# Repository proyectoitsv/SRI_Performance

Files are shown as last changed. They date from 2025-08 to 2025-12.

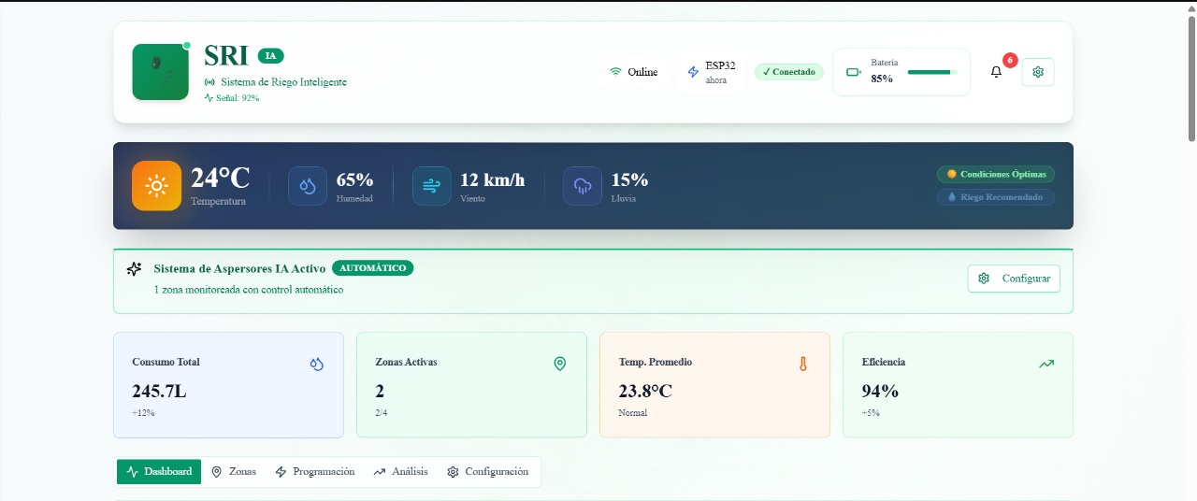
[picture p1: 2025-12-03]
INTERFAZ GRAFICA/IMAGEN_INTERFAZ1.jpg

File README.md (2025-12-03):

# SRI Performance
Sistema de Riego Inteligente sectorizado y autónomo.

## Descripción
SRI Performance es un sistema de riego inteligente que utiliza un ESP32, sensores de humedad y un aspersor direccionable en dos ejes (X–Y) para regar únicamente donde es necesario. Optimiza el uso del agua y mantiene el césped saludable sin intervención constante.

## Características
- Riego automático basado en humedad real del suelo.
- Aspersor 2D (X–Y) para direccionar el riego por sectores.
- Control desde pantalla local o mediante Wi-Fi/Bluetooth.
- Ahorro de agua superior al 20–40% en comparación con métodos tradicionales.
- Instalación prolija con cañerías y cableado subterráneo.
- Seguridad: evita encharcado, bloqueos y riego en horarios inadecuados.

## Tecnologías utilizadas
**Hardware:** ESP32, servomotores, bomba de agua, aspersor direccionable, display.  
**Sensores:** humedad de suelo, temperatura ambiente.  
**Software:** Arduino IDE / PlatformIO.  
**Comunicación:** Wi-Fi y Bluetooth.

## Funcionamiento
1. Los sensores miden humedad y temperatura.  
2. El ESP32 evalúa si es necesario regar.  
3. El aspersor se mueve hacia el sector requerido.  
4. La bomba activa el riego únicamente en esa zona.  
5. El sistema se detiene al alcanzar la humedad adecuada.

## Impacto esperado
- Ahorro significativo de agua en jardines y espacios residenciales.  
- Reducción de costos de mantenimiento.  
- Uso más responsable de los recursos hídricos.

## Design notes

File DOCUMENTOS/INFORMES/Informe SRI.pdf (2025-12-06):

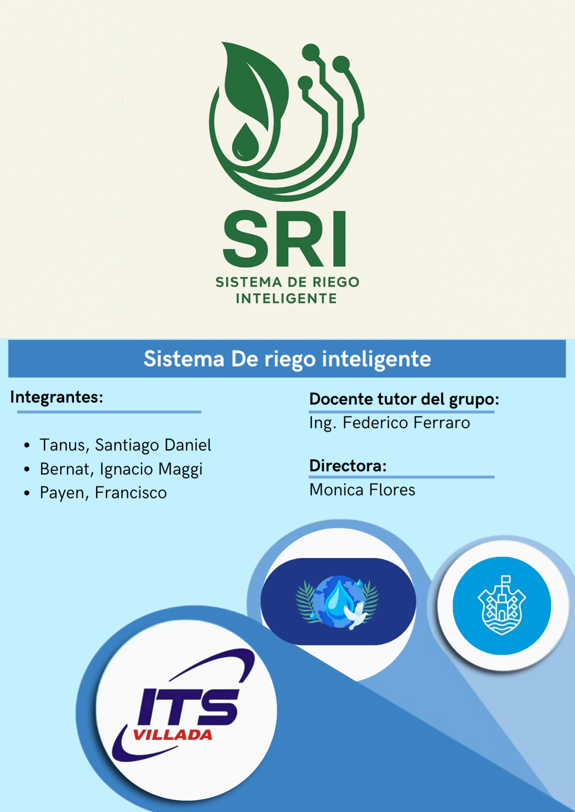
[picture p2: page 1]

Proyecto Final Electronica - ITS Villada 2025
“Miles han vivido sin amor,

# ninguno sin agua ”

### - W. H. Auden

# Introducción

El presente informe forma parte del Proyecto Final del Instituto Técnico Salesiano Villada. Este documento busca plasmar el recorrido del proceso llevado a cabo por el equipo de estudiantes, quienes asumieron el desafío de abordar una problemática real vinculada al uso ineficiente del agua en entornos urbanos y proponer una solución tecnológica que responda a las necesidades identificadas.

El proyecto seleccionado consiste en el diseño y construcción de un Sistema de Riego Inteligente (SRI) orientado al riego de césped y jardines domiciliarios. La propuesta combina electrónica, programación y criterios agronómicos con el objetivo de optimizar el consumo de agua potable, manteniendo a la vez la calidad de los espacios verdes y reduciendo el impacto ambiental asociado al desperdicio hídrico.

El proceso de trabajo se enmarca en un enfoque metodológico que abarcó desde la identificación y análisis del problema hasta la conceptualización, diseño, construcción y validación de un prototipo funcional. Este camino permitió aplicar los conocimientos adquiridos en áreas como electrónica, programación, diseño técnico y automatización, consolidando así las competencias propias del perfil profesional técnico.

La búsqueda de soluciones se realizó teniendo en cuenta criterios de factibilidad, impacto y utilidad. El sistema propuesto no solo incorpora innovación y tecnología, sino que además se alinea con principios de sostenibilidad y uso responsable del agua, aportando una herramienta concreta ante una problemática ambiental vigente.

# Análisis de la problemática

### 1.1 Contexto hídrico global y urbano

El agua potable recorre un largo trayecto desde las plantas purificadoras hasta los hogares, donde se destina a usos esenciales como la higiene, la alimentación y el saneamiento. Sin embargo, diversos estudios señalan que una fracción considerable de este recurso se destina a usos no vitales y, en muchos casos, bajo esquemas de consumo poco eficientes.

En el ámbito urbano, el riego de césped y jardines representa uno de los principales focos de consumo dentro del uso domiciliario. La Environmental Protection Agency (EPA) estima que el riego de césped puede representar hasta el 60 % del consumo total de agua de un hogar. En un contexto de creciente escasez hídrica, este porcentaje adquiere un peso crítico.

### 1.2 Riego residencial en Córdoba

ITS Villada | 1.

En la provincia de Córdoba se observa una expansión sostenida de barrios privados y urbanizaciones con superficies importantes de césped y espacios verdes. Tomando como referencia que, para 2022, existían aproximadamente 90 barrios privados, cada uno con un promedio de 300 lotes, se puede dimensionar el impacto del riego sobre el consumo de agua.

Suponiendo que cada vivienda posee unos 100 m² de césped y un riego diario promedio de 5 L/m², se obtiene:

### 90 barrios × 300 lotes × 100 m² × 5 L/m² = 13.500.000 L/día

Este volumen representa únicamente el consumo vinculado al riego domiciliario en barrios privados, sin considerar otros sectores urbanos. Si se asume una eficiencia típica de los sistemas de riego convencionales cercana al 80 %, alrededor de 2,7 millones de litros diarios no se aprovechan correctamente y se pierden por evaporación, drenaje excesivo o malas prácticas de riego.

A lo anterior se suman las viviendas dentro de la ciudad de Córdoba que utilizan riego manual —tradicionalmente menos eficiente—, lo cual incrementa aún más el consumo y las pérdidas totales de agua.

### 1.3 Procesos actuales de riego

En entornos residenciales predominan dos modalidades principales:

- Riego manual, mediante manguera, sin medición de caudal ni control preciso del tiempo.
- Riego automático por aspersores, gobernados por temporizadores que habilitan la apertura del sistema en horarios fijos.

Si bien los aspersores controlados por temporizador presentan una mejor eficiencia que el riego manual, todavía dejan un margen importante de ineficiencia.

# ¿Qué consecuencias tiene?

La pérdida de recursos hídricos en el entorno urbano tiene consecuencias graves que afectan tanto al medio ambiente como a la gestión del recurso.

### 2.1 Impactos ecológicos

El uso ineficiente del agua potable en el riego de césped y jardines tiene impactos ambientales directos:

- Desperdicio de recursos hídricos: Se incrementa la presión sobre las fuentes de abastecimiento, especialmente en períodos de sequía.
- Alteración del ciclo hidrológico urbano: El exceso de riego genera escorrentía superficial que arrastra fertilizantes y contaminantes hacia desagües pluviales y cursos de agua.
ITS Villada | 2.

- Degradación del suelo: El sobre-riego puede deteriorar la estructura del suelo, reducir su capacidad de infiltración y favorecer la erosión, además de lixiviar nutrientes.

### 2.2 Impactos socioeconómicos

Desde el punto de vista socioeconómico, la ineficiencia hídrica implica:

- Aumento del costo del servicio de agua para los usuarios domiciliarios.
- Incremento de la demanda energética asociada a la potabilización, bombeo y distribución de mayores volúmenes de agua.
- Limitaciones y conflictos de uso en épocas críticas, donde los municipios suelen imponer restricciones de riego.

### 2.3 Impactos a nivel urbano y global

A escala urbana y global, el uso ineficiente del agua para riego contribuye a:

- Agravar el estrés hídrico en regiones vulnerables, reduciendo la disponibilidad de agua para usos esenciales.
- Aumentar la huella hídrica de las ciudades.
- Dificultar el cumplimiento de objetivos de sostenibilidad vinculados al uso racional del agua, como el ODS 6 de la Agenda 2030.

# ¿Cómo se puede mejorar la eficiencia del riego?

Existen diversas estrategias para mitigar el uso ineficiente del recurso hídrico.

### 3.1 Modernización y regulación del riego domiciliario

- Implementar sistemas de riego automatizados con sensado real del suelo y del ambiente.
- Regular horarios de riego para evitar pérdidas por evaporación en horas de máxima temperatura.
- Promover ordenanzas municipales que incentiven el uso de tecnologías eficientes.

### 3.2 Alternativas tecnológicas sostenibles

- Incorporar sensores de humedad del suelo y sensores ambientales para regar solo cuando es necesario.
- Utilizar microcontroladores con conectividad, como el ESP32, que permitan monitoreo y control remoto.
- Fomentar la adopción de sistemas de riego por goteo o aspersores de bajo caudal.

### 3.3 Manejo del suelo y programación del riego

- Ajustar la frecuencia de riego en función del tipo de suelo (arenoso, franco, arcilloso) y de la pendiente.
- Programar riegos en franjas horarias de baja evaporación.
ITS Villada | 3.

# Investigación

Se inició el proceso de investigación partiendo de la identificación de una problemática ambiental de relevancia global. Entre los distintos desafíos, se destacó la creciente escasez de agua dulce, un recurso cuya disponibilidad se ve comprometida debido al cambio climático, el crecimiento poblacional y el uso ineficiente en diversos sectores. A partir de este punto de partida, se llevó a cabo un análisis más profundo para comprender en qué ámbitos urbanos se produce un consumo excesivo o poco controlado del agua.

Durante esta etapa se revisaron distintos hábitos y sistemas de uso cotidiano, tales como el consumo doméstico, los procesos industriales y el mantenimiento de espacios verdes. Fue en este último donde se detectó un patrón significativo: el riego de césped y jardines presenta altos niveles de desperdicio debido a prácticas poco eficientes, falta de automatización, escasa supervisión y desconocimiento sobre las necesidades reales de humedad del suelo.

Como resultado de esta investigación, se identificó que el riego manual o los sistemas tradicionales suelen aportar más agua de la necesaria, generando no solo un gasto innecesario del recurso, sino también problemas asociados como el deterioro del césped, el aumento del consumo energético y el impacto económico en los hogares. Este hallazgo se convirtió en el eje central del proyecto, orientado a desarrollar soluciones más inteligentes y sostenibles para el manejo del agua en espacios verdes urbanos.

## Espacios verdes

Tomando como referencia que, para el año 2022, existían aproximadamente 90 barrios privados en la provincia de Córdoba, y considerando que cada uno de ellos cuenta en promedio con unos 300 lotes, es posible estimar el impacto del riego domiciliario de césped sobre el consumo total de agua. Si asumimos que cada vivienda posee alrededor de 100 m² de superficie con césped y que el riego promedio diario requerido es de unos 5 litros por metro cuadrado, se obtiene el siguiente cálculo:

90 barrios × 300 lotes × 100 m² × 5 L/m² = 13.500.000 litros de agua por día.

Este volumen representa únicamente el consumo de las viviendas que utilizan riego automático dentro de barrios privados, sin considerar otros sectores urbanos. Además, si se asume un nivel de eficiencia típico de los sistemas de riego convencionales, cercano al 80%, se puede estimar la magnitud del desperdicio asociado. Un 20% del agua aplicada no llega a aprovecharse debido a pérdidas por evaporación, drenaje excesivo, mala orientación de los aspersores o prácticas de riego inadecuadas.

Esto significa que, de los 13,5 millones de litros utilizados diariamente, aproximadamente 2,7 millones de litros se pierden sin cumplir su función real. Para dimensionar esta cifra, basta con señalar que este volumen equivale, en promedio, al contenido de una pileta olímpica completa desperdiciada cada día.

Cabe destacar que estos cálculos no incluyen a las miles de viviendas ubicadas dentro de la ciudad de Córdoba que también poseen superficies de césped y utilizan riego manual —un método tradicionalmente menos eficiente—, lo que incrementaría aún más el consumo y las pérdidas totales de agua. Este escenario evidencia la necesidad urgente de implementar tecnologías de riego más inteligentes, eficientes y automatizadas que permitan optimizar el uso del recurso y reducir el impacto ambiental asociado.

ITS Villada | 4.

## Procesos actuales de riego

Se analizaron los procesos de riego actualmente utilizados en entornos residenciales y urbanos. Entre ellos, los más comunes son el riego manual y los sistemas de riego automático por aspersores. Si bien estos últimos presentan una mayor eficiencia, con valores que oscilan entre el 75% y el 85%, todavía dejan un margen de ineficiencia de aproximadamente 15%, que al ser extrapolado a grandes superficies representa un volumen significativo de agua desperdiciada.

A partir de este diagnóstico, se inició una búsqueda de alternativas que permitieran incrementar la eficiencia del riego y reducir el desperdicio, poniendo especial atención en las limitaciones que presentan los sistemas actuales. Entre los principales factores identificados se encontró que la mayoría de las instalaciones no considera adecuadamente las variables ambientales que influyen en las necesidades reales de agua del césped, tales como la humedad del suelo, la temperatura ambiente, la radiación solar y la evapotranspiración.

Con el fin de diseñar una solución más precisa y sustentada, se investigó cuál es el tipo de césped más común en la región de Córdoba y cuáles son sus requerimientos hídricos. En particular, se determinó el porcentaje de humedad volumétrica necesario para mantener el césped saludable, así como el valor mínimo en el que la planta alcanza su punto de marchitez permanente, momento en el cual ya no puede recuperarse aun si se la riega posteriormente. Esta información resulta fundamental para definir umbrales de riego inteligentes.

Asimismo, se llevó a cabo una revisión de los tipos de suelo predominantes en la región, dado que la textura, estructura y capacidad de retención hídrica del suelo influyen directamente en la frecuencia y cantidad de riego necesaria. También se incorporó el valor de evapotranspiración (ET) propio de la zona, un parámetro clave que permite estimar la pérdida de agua del suelo y la planta por evaporación y transpiración.

Finalmente, se evaluaron las temperaturas y franjas horarias más convenientes para realizar el riego, priorizando momentos del día en los que la evaporación es mínima (como la madrugada o la noche) y en los que el funcionamiento del sistema no genera molestias para los propietarios. Esta investigación permitió establecer criterios técnicos más precisos para el desarrollo de un sistema de riego automatizado, eficiente y adaptado a las condiciones locales.

ITS Villada | 5.

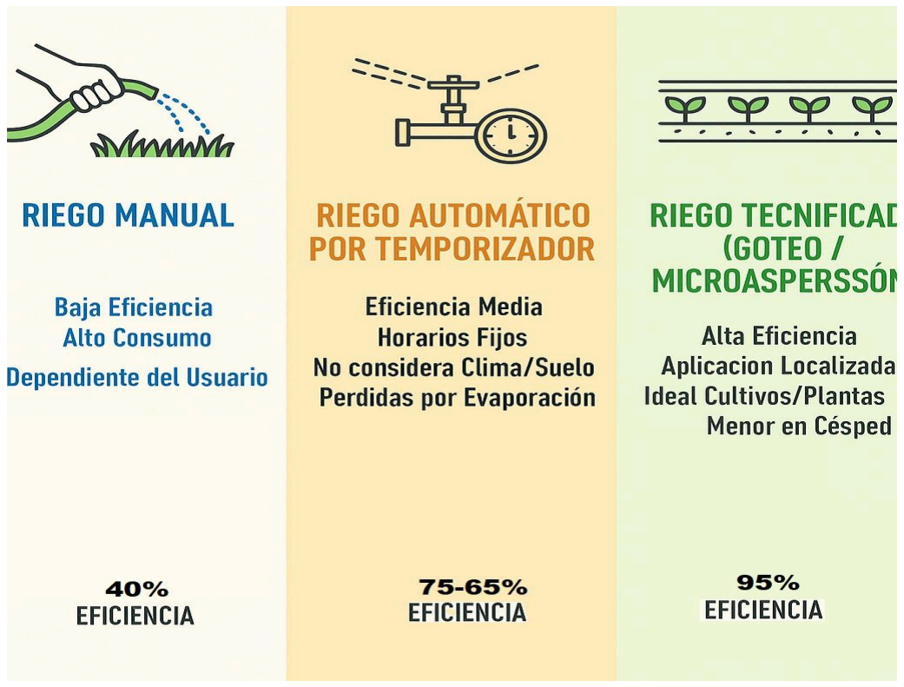
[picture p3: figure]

Figura 1: “Comparativa de sistemas de riego actuales.”

# Solución elegida

Frente a la problemática planteada, se eligió el desarrollo de un Sistema de Riego Inteligente (SRI) como solución tecnológica. La propuesta se enfoca en el ámbito domiciliario y busca:

1. Optimizar el uso del agua en el riego de césped.
2. Integrar sensado de suelo y ambiente.
3. Automatizar la decisión de riego en función de variables reales.

# Sistema de riego propuesto

El Sistema de Riego Inteligente desarrollado consiste en un aspersor automatizado controlado por un microcontrolador ESP32, equipado con:

- Sensores de humedad de suelo
- Sensor de temperatura y humedad ambiente
- Bomba de agua
- Servomotores para orientar el chorro de riego.

El objetivo es lograr un riego sectorizado, que aplique el agua únicamente donde y cuando es necesario, manteniendo la humedad del suelo por encima del 15%

ITS Villada | 6.

# Características del producto mínimo viable

Para garantizar el rendimiento óptimo de nuestro SRI, es esencial incorporar ciertas características fundamentales:

- Medición Inteligente de Humedad: Capacidad de medir con precisión la humedad del suelo en al menos tres puntos, para detectar heterogeneidades y optimizar la distribución del agua.
- Mecanismo Controlado para el Riego: El sistema debe habilitar el riego de forma proporcional a la necesidad, controlando la bomba y la orientación de los aspersores para lograr una cobertura uniforme.
- Sistema de Telemetría: Integración de un sistema que facilite la transmisión de datos en tiempo real (humedad, temperatura, estado de la bomba) y permita una respuesta efectiva desde la estación terrena.
- Sistemas de Orientación: Utilización de servomotores para garantizar la precisión de la ubicación donde se aplica el agua, evitando el riego de áreas no deseadas.
- Estación Terrena: Base operativa para recolectar, monitorear y tomar decisiones sobre el avance del riego. Esta estación recibe los datos telemétricos y permite realizar ajustes en tiempo real.

# Consumo de agua y estimación de ahorro

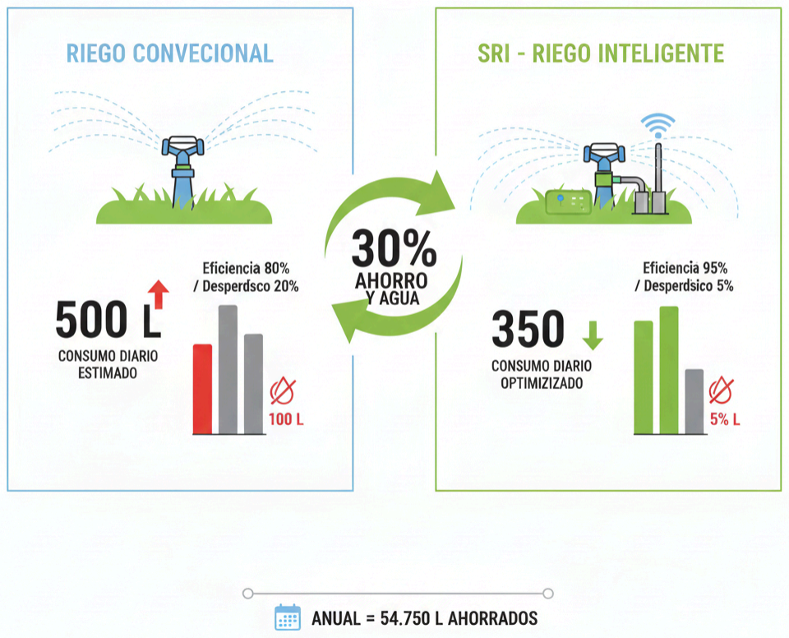
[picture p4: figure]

Figura 2: “Comparativa de consumo hídrico entre sistema convencional y sri.”

ITS Villada | 7.

# Escenario de aplicación

El sistema se dimensionó inicialmente para jardines de entre 50m2 y 150m2 , con tres zonas de riego diferenciadas controladas por la orientación del aspersor.

No obstante, el concepto es escalable a:

- Clubes deportivos
- Espacios verdes
- Pequeñas plazas de barrio.

# Funcionamiento en conjunto

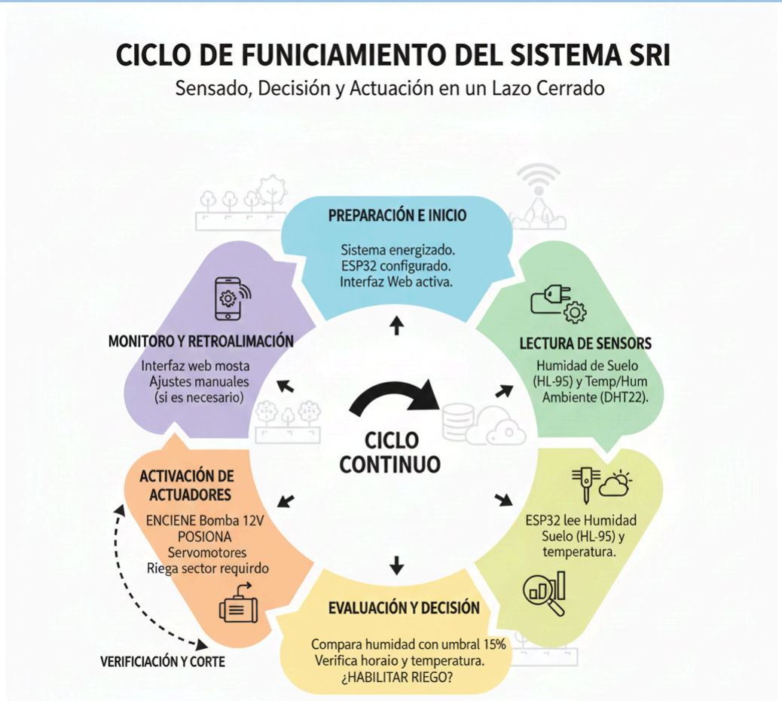
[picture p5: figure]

Figura 3: “Diagrama de flujo de funcionamiento.”

ITS Villada | 8.

# Relevamiento de componentes del sistema

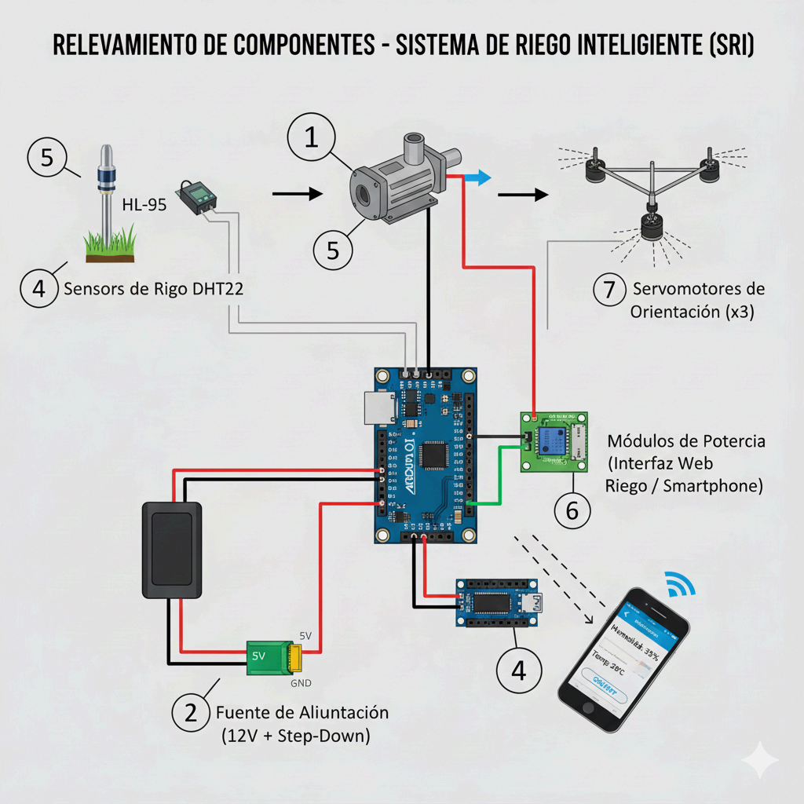
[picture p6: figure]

Figura 4: “Relevamiento de componentes.”

Relevamiento de Componentes del Sistema
1. Microcontrolador Principal - Es el cerebro del sistema. Se encarga de adquirir los datos de los sensores, ejecutar la lógica de decisión de riego (basada en el umbral de humedad) y enviar las señales de control a los actuadores y módulos de potencia.
- Utilizado: ESP32 (Módulo de desarrollo con conectividad WiFi integrada).
2. Sensores de Humedad de Suelo - Miden la resistencia eléctrica del suelo, proporcionando un valor analógico que se correlaciona con el contenido hídrico y permite determinar si se ha alcanzado el umbral crítico para el césped.
- Utilizados: Sensores HL-95 (Resistivos).
3. Sensor Ambiental - Captura las condiciones atmosféricas (temperatura y humedad relativa) que se utilizan como criterios adicionales para habilitar o restringir el riego (ej., evitar riego en condiciones de alta evaporación).
- Utilizado: Sensor DHT22 (Temperatura y Humedad ambiente).
4. Actuador de Riego (Bomba) - Genera el caudal de agua necesario para la aplicación en los sectores del jardín.
- Utilizado: Bomba de agua $12~V~DC$ con caudal nominal de $2~L/min$.
5. Servomotores de Orientación - Controlan la posición angular del aspersor en los ejes horizontal (azimut) y vertical (elevación) para lograr la sectorización del riego.
- Utilizados: Tres Servomotores estándar de $5~V$.
ITS Villada | 9.

6. Módulo de Potencia (Control de Bomba) - Aísla la etapa de control de bajo voltaje del ESP32 de la etapa de potencia de la bomba, asegurando que se entregue la corriente adecuada al actuador de riego.
- Utilizados: Relé y etapa de excitación con transistor BC337 y diodo de protección.
7. Fuente de Alimentación - Proporciona la energía requerida por todo el sistema, incluyendo el microcontrolador y los actuadores.
- Utilizada: Fuente de alimentación 12v (para la bomba y alimentación general) y módulo step down (para el ESP32 y servos).
8. Interfaz de Usuario/Estación Terrena - Permite el monitoreo en tiempo real de los datos (humedad, temperatura) y la emisión de comandos manuales o de configuración al sistema.
- Utilizado: Servidor Web implementado directamente en el ESP32 (accesible vía red local WiFi).

# Hardware

El diseño del hardware surge directamente de los resultados obtenidos en la etapa de investigación, donde se identificaron los principales factores que afectan la eficiencia del riego residencial: falta de control de humedad real del suelo, ausencia de retroalimentación térmica, pérdidas por evaporación, escurrimiento superficial y heterogeneidad de suelos típicos de Córdoba. Por ello, el hardware no se pensó como un sistema aislado, sino como una plataforma capaz de medir, interpretar y responder a las necesidades hídricas reales del césped Tifway, el más común en la región.

Durante la investigación se determinó que el césped Tifway requiere mantener un nivel mínimo de humedad del 15% para mantenerse saludable y 5% para evitar alcanzar el punto de marchitez permanente, situación que provocaría daños irreversibles incluso si se reanuda el riego. Esta condición crítica, sumada a la variabilidad en la capacidad de retención de agua de los suelos locales (francos, arenosos y arcillosos), definió la necesidad de sensores confiables y una lógica de control rápido.

El componente central de este diseño es el microcontrolador ESP32, elegido por su equilibrio entre capacidad de procesamiento, conectividad WiFi nativa, bajo consumo y amplia disponibilidad. Su arquitectura de doble núcleo permite ejecutar simultáneamente la lectura de sensores, el servidor web y el control del riego sin comprometer la estabilidad del sistema, una característica indispensable si se considera que la falta de riego durante varias horas podría llevar al césped por debajo de su umbral crítico.

El monitoreo del suelo se realiza mediante tres sensores de humedad HL-69 (Prototipo), dispuestos estratégicamente para cubrir zonas con diferencias en exposición solar, compactación y textura del sustrato. Esta elección responde a un aspecto muy relevante identificado en la investigación: el césped no se humedece de forma uniforme y el riego tradicional no corrige esas variaciones. Los HL-69, aun no siendo de grado profesional,

ITS Villada | 10.

permiten detectar tendencias de humedad y definir curvas de calibración específicas para cada tipo de suelo estudiado. Su señal analógica es compatible con los ADC de 12 bits del ESP32, permitiendo una reconstrucción precisa de los porcentajes de humedad.

La variable temperatura fue incorporada a partir del análisis de evapotranspiración y eficiencia hídrica, que demuestra que regar con temperaturas elevadas produce pérdidas inmediatas por evaporación. Para ello se integró un sensor digital DHT22, capaz de registrar temperatura y humedad ambiente con buena estabilidad y bajo tiempo de respuesta. Esta medición permite condicionar el riego a ventanas térmicas adecuadas (por ejemplo, durante la madrugada), siguiendo las recomendaciones identificadas en la etapa de investigación.

Para la orientación del chorro de riego se diseñó un mecanismo tridimensional compuesto por tres servomotores controlados por PWM: dos para el eje vertical y uno para el eje horizontal. Esta capacidad de movimiento responde directamente a los problemas detectados en los sistemas tradicionales de aspersión, donde la falta de direccionamiento produce solapamientos de agua y zonas regadas innecesariamente. Con este sistema se garantiza una dosificación precisa del agua, evitando desperdicios y adaptándose a la forma real del terreno.

Finalmente, el sistema hidráulico está compuesto por una bomba de 12 V con un caudal de 2 L/min, valor adecuado para riego sectorizado y consistente con el requerimiento hídrico calculado para 1 m² de césped en un ciclo controlado. Su consumo reducido evita sobrecargar la fuente, mientras que su presión es suficiente para generar un chorro direccionable sin provocar escurrimientos (problema habitual en suelos arcillosos con baja infiltración).

En conjunto, el hardware del sistema se diseñó para ser compacto, replicable en entornos domésticos y totalmente coherente con los fenómenos agronómicos analizados en la investigación, garantizando una operación sustentable y eficiente del recurso hídrico.

# Firmware

El firmware desarrollado para el Sistema de Riego Inteligente constituye el componente operativo responsable de ejecutar la lógica interna definida en la investigación agronómica. Su función principal es integrar de forma continua las variables del entorno —temperatura ambiente y humedad del suelo— con los criterios de eficiencia hídrica obtenidos previamente, para así tomar decisiones dinámicas sobre la activación del riego sectorizado. Este diseño no se limita a leer sensores y actuar dispositivos, sino que implementa un modelo de control en tiempo real que busca optimizar el uso del agua en función del comportamiento fisiológico del césped Tifway y de las condiciones climáticas locales.

Desde un punto de vista arquitectónico, el firmware se estructura sobre la plataforma ESP32 bajo el entorno Arduino, aprovechando su doble núcleo, su capacidad de manejo de interrupciones y su soporte para múltiples periféricos simultáneos. El programa inicia con la declaración de entradas y salidas, constantes físicas, canales PWM y variables globales que almacenan el estado del sistema. Esta organización facilita un procesamiento eficiente y

ITS Villada | 11.

reduce tiempos de respuesta, un aspecto crítico considerando que el sistema debe mantener lecturas actualizadas incluso durante la ejecución del riego.

En la fase de inicialización, dentro de setup(), se configuran los pines correspondientes a los sensores de humedad del suelo, el sensor de temperatura DHT22, la bomba de agua y el LED indicador del estado horario. Paralelamente, se establecen tres canales PWM independientes para controlar la posición de los servomotores. Aquí radica un aspecto técnico relevante: la elección de una frecuencia de 50 Hz y una resolución de 16 bits permite generar señales con un nivel de granularidad muy superior al de un control PWM convencional. Esta resolución elevada es indispensable para lograr movimientos suaves y repetibles del aspersor, garantizando que cada sector del césped reciba un aporte hídrico uniforme y sin solapamientos.

La conexión WiFi se ejecuta al inicio, permitiendo que el ESP32 opere como un nodo en la red doméstica del usuario. Esta conexión es esencial para habilitar el servidor web interno del sistema, el cual entrega datos en tiempo real sobre las condiciones ambientales y el estado del riego. Poco después, se sincroniza la hora local mediante un servidor NTP. Esta sincronización no cumple un rol meramente informativo: está directamente vinculada a los hallazgos de la investigación sobre evapotranspiración, en los cuales se demostraron franjas horarias significativamente más eficientes para regar. El firmware utiliza esta información para activar o bloquear el riego según si el horario se encuentra dentro de estas ventanas óptimas.

Una vez inicializado, el ciclo loop() mantiene el funcionamiento operativo en tiempo real. En cada iteración se atienden solicitudes del servidor web y se verifica si la franja de riego está activa. Esta variable —franja_OK— se actualiza consultando el reloj interno previamente sincronizado. La validación se efectúa comparando la hora actual con las franjas definidas entre las 05:30 y 09:30, y nuevamente entre las 22:00 y 00:00. Estas zonas horarias fueron seleccionadas por presentar condiciones de baja evaporación y temperaturas moderadas, condiciones que maximizan la eficiencia en la absorción de agua por parte del césped.

Cuando la franja es válida, el firmware procede a adquirir datos ambientales mediante la función get_data(). En esta función se ejecuta la lectura de los sensores de humedad HL-69 mediante el ADC del ESP32. Las lecturas de voltaje son transformadas a porcentaje de humedad mediante una ecuación de calibración obtenida experimentalmente, ajustada a las propiedades físicas de los suelos analizados en la investigación. Esta conversión es fundamental, ya que los sensores capacitivos presentan una respuesta no lineal que debe ser corregida para obtener valores interpretables y comparables entre sectores. Paralelamente, el sensor de temperatura DHT22 proporciona una medida precisa en grados Celsius. Esta variable actúa como restricción térmica dentro de la lógica del programa, ya que el riego solo se habilita cuando la temperatura se sitúa en un rango considerado fisiológicamente adecuado para evitar pérdidas excesivas por evaporación (aproximadamente entre 10 °C y 25 °C).

La lógica de riego se estructura en tres funciones independientes, cada una correspondiente a un sector físico del terreno. Cada función evalúa las mismas condiciones ambientales, pero ejecuta diferentes configuraciones de posicionamiento para los servomotores. El diseño del sistema permite orientar el aspersor con precisión hacia tres regiones específicas, asignando a cada una un conjunto único de valores PWM. Esta adaptación física del chorro de agua

ITS Villada | 12.

responde directamente a los problemas detectados en los sistemas tradicionales, donde la falta de dirección provoca tanto sobre-riego como sub-riego según la geometría del terreno.

Una vez que el firmware detecta que un sector presenta una humedad inferior al umbral de 60 % —valor identificado en la investigación como indicador de agotamiento hídrico incipiente— se procede a activar la bomba y posicionar los servos en su orientación correspondiente. A partir de este momento, la función entra en un ciclo de control en el cual monitorea continuamente la humedad del suelo hasta que esta alcanza aproximadamente el 80 %, nivel considerado adecuado para asegurar una hidratación uniforme sin generar saturación del sustrato. Durante este proceso, el sistema no descuida sus funciones paralelas: el servidor web sigue operativo, lo que permite al usuario visualizar los cambios incluso mientras el riego está en marcha.

La gestión del servidor web constituye otro de los puntos técnicos destacables. La interfaz HTML se aloja directamente en el ESP32, y mediante funciones JavaScript que se ejecutan en el navegador del usuario, la información se actualiza automáticamente cada dos segundos utilizando peticiones al endpoint "/datos". Este mecanismo posibilita una monitorización constante del sistema sin necesidad de interfaces externas ni aplicaciones adicionales. El servidor envía la información en formato JSON, lo cual facilita su integración, procesamiento y visualización en cualquier dispositivo con capacidad de navegación.

En términos generales, el firmware fue diseñado no solo para operar como un sistema reactivo, sino para comportarse como un controlador inteligente que toma decisiones basadas en condiciones ambientales reales, modelos agronómicos y restricciones temporales. La combinación de sensores calibrados, control PWM avanzado, procesamiento en tiempo real, sectorización hidráulica y visualización remota conforma un sistema de riego autónomo con capacidad de adaptarse a las necesidades específicas del terreno y del césped. Su diseño implementa de manera precisa los principios de agricultura inteligente, integrando eficiencia hídrica, sostenibilidad y facilidad de uso en un único sistema embebido.

Link para ver diagrama de flujo: https://github.com/proyectoitsv/SRI_Performance/blob/main/DISE%C3%91O%20SISTEMAS/DIAGRAMAS/diagrama%20flujo.mmd

# Impacto

El Sistema de Riego Inteligente contribuye al impulso de la calidad de vida de los ciudadanos y la mejora del entorno.

- Uso Responsable del Recurso: Instala la temática del uso responsable del agua en el ámbito doméstico, reduciendo la presión sobre las fuentes de abastecimiento.
- Ahorro Económico: Reduce los costos de servicio para las familias al optimizar el consumo.
- Bienestar Social: Mejora la calidad de los espacios verdes, relevantes para la recreación y el bienestar, promoviendo el cuidado del medio ambiente urbano.
ITS Villada | 13.

El proyecto demuestra cómo, desde una escuela técnica, puede generarse una propuesta concreta con impacto social y ambiental positivo.

# Marco Jurídico del proyecto

El SRI se alinea con la normativa nacional y provincial referida a la gestión eficiente del recurso hídrico , encontrando un panorama favorable para su desarrollo.

- Uso Racional: El sistema cumple con los principios de uso racional de recursos naturales y gestión ambiental del agua.
- Regulación de Servicios: En una etapa posterior, el sistema podría registrarse como modelo de utilidad y el software asociado como obra protegida por derechos de autor.
- Cumplimiento de Políticas: El proyecto se beneficia de las políticas que buscan fomentar la construcción de redes automatizadas y el desarrollo de tecnologías relacionadas con el cuidado del agua.

# Mejoras a Futuro

Si bien el Sistema de Riego Inteligente desarrollado presenta un funcionamiento eficiente, autónomo y coherente con los criterios agronómicos analizados, existen diversas líneas de evolución tecnológica que permitirían ampliar significativamente su alcance, robustez y capacidad de adaptación. A continuación, se detallan las mejoras más relevantes que podrían incorporarse en futuras versiones del sistema.

### 1. Integración con un servidor web externo

En la versión actual, el servidor web se ejecuta de manera local dentro del ESP32, lo que limita el acceso del usuario a la red interna del domicilio. Una mejora sustancial sería migrar el sistema hacia un servidor web externo, alojado en la nube o en un servidor remoto. Esta mejora permitiría:

Acceso al sistema desde cualquier lugar del mundo, sin necesidad de estar conectado a la red WiFi local.

Registro histórico de datos de humedad, temperatura y ciclos de riego.

Sincronización continua de parámetros y actualizaciones del firmware “over the air” (OTA).

Posibilidad de implementar usuarios, contraseñas y autenticación avanzada para mayor seguridad.

La arquitectura se podría basar en protocolos como MQTT, HTTPS o WebSockets, junto con bases de datos en la nube (Firebase, InfluxDB o PostgreSQL), permitiendo desarrollar un ecosistema escalable y multidispositivo.

ITS Villada | 14.

### 2. Interfaz web avanzada y multiplataforma

La interfaz actual cumple una función informativa básica; sin embargo, puede evolucionarse hacia una plataforma web avanzada, con mayores capacidades de visualización y control:

Implementación de gráficos en tiempo real para humedad, temperatura y consumo de agua.

Panel de control interactivo para activar o desactivar sectores manualmente.

Configuración dinámica de umbrales, franjas horarias, tipos de suelo o parámetros de riego.

Sistema de notificaciones (e-mail, Telegram o notificaciones push) para alertar al usuario ante condiciones críticas como humedad extremadamente baja o fallas de sensores.

Diseño responsivo compatible con dispositivos móviles, tablets y computadoras.

El uso de frameworks como React, Vue o Svelte, junto con una API REST centralizada, permitiría crear una experiencia de usuario profesional, escalable y mucho más versátil.

### 3. Conexión a servicios meteorológicos externos

Una mejora de alto impacto funcional consiste en integrar la plataforma con servicios meteorológicos en línea, tales como OpenWeatherMap, Argentina.gob.ar Meteorología, AccuWeather o WeatherAPI. Esta integración posibilitará optimizar la toma de decisiones basándose no solo en mediciones locales, sino también en pronósticos y alertas meteorológicas.

Las ventajas principales de esta funcionalidad incluyen:

Anticipación automática a lluvias próximas, evitando riegos innecesarios y reduciendo consumo de agua.

Ajuste dinámico de la frecuencia e intensidad del riego según condiciones forecast (temperatura máxima del día siguiente, humedad ambiente prevista, radiación solar estimada).

Incorporación de índices agronómicos derivados, como evapotranspiración potencial (ET₀) basada en modelos climáticos.

Activación de “modo ahorro” en días nublados o fríos donde la demanda hídrica disminuye.

El ESP32 podría consultar estos servicios mediante peticiones HTTP o MQTT, interpretando los datos meteorológicos para complementar los sensores locales y generar un sistema híbrido más inteligente y predictivo.

Conclusión general de mejoras

ITS Villada | 15.

La integración de estas mejoras a futuro transformaría el sistema de un dispositivo autónomo local a una plataforma completa de riego inteligente conectada, con capacidad de análisis avanzado, control remoto, toma de decisiones predictiva y experiencia de usuario profesional. Estas extensiones permitirían aumentar la eficiencia hídrica, escalar el sistema a terrenos más grandes y mejorar su utilidad tanto en contextos residenciales como en aplicaciones semi-profesionales.

## Prototipo

El prototipo desarrollado consiste de solo 3 sensores de humedad para demostrar su funcionamiento y su rango ya que no se dispone de un espacio lo suficientemente grande para usar mas, y no es necesario tampoco.

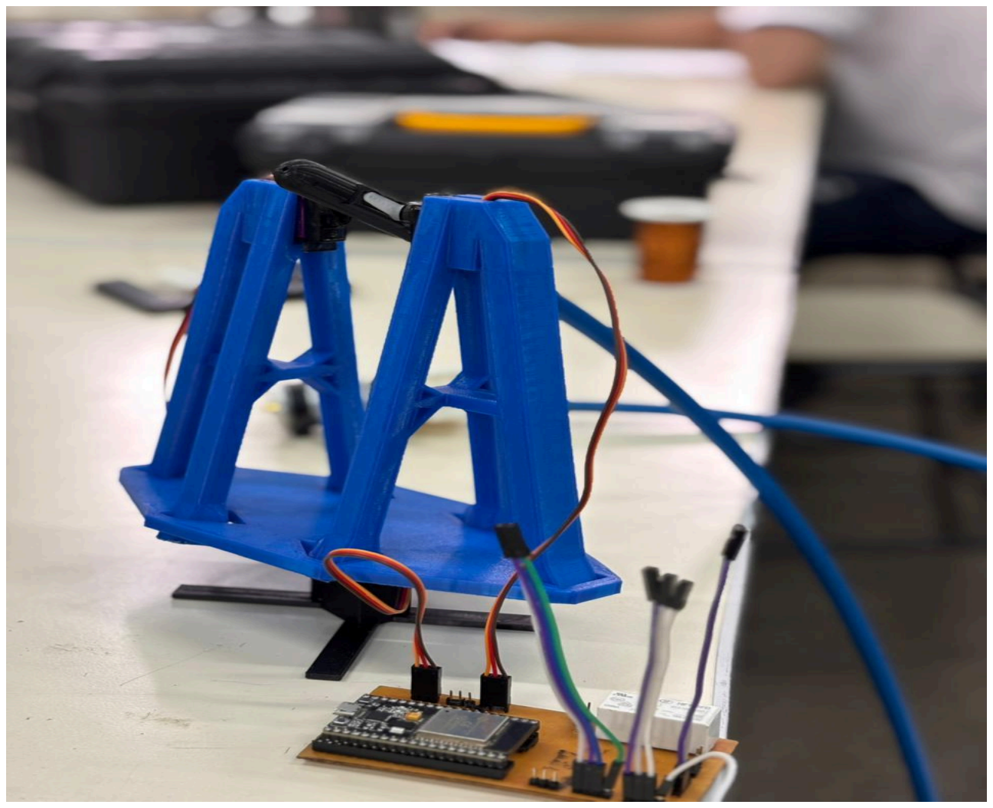
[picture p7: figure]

Figura 5: “Prototipo real del proyecto.”

# Conclusión

El proyecto presentado tuvo como objetivo principal el desarrollo de un Sistema de Riego Inteligente (SRI) para contrarrestar la problemática actual del uso ineficiente del agua potable en el riego de césped y jardines en entornos urbanos. A lo largo del informe, se explicó la urgencia de la problemática hídrica en Córdoba y cómo la automatización puede ayudar a reducir sus efectos negativos, tanto ecológicos como socioeconómicos. También se analizaron diferentes métodos de riego existentes y se justificaron las ventajas de utilizar tecnología de sensado para mejorar la eficiencia del proceso.

El diseño del proyecto incluye una solución técnica robusta, integrando el microcontrolador ESP32, sensores de humedad HL-95 y servomotores para el control sectorizado. La solución propuesta se diseñó para superar los sistemas de riego por temporizador, basando la decisión en parámetros agronómicos reales, como el umbral de humedad. Además, se realizaron cálculos detallados de la estimación de ahorro de agua, demostrando la viabilidad económica y ambiental del sistema.

ITS Villada | 16.

En cuanto a la metodología de trabajo, se utilizó la plataforma JIRA para la organización eficiente de tareas y GitHub para la documentación y el control de versiones del código. El proceso de diseño y desarrollo demostró cómo se abordaron los problemas de ingeniería electrónica, mecánica e hidráulica, permitiendo la mejora continua del diseño hasta el prototipo final.

En resumen, este proyecto no solo representó un desafío técnico integral, sino también una gran oportunidad para aplicar los conocimientos adquiridos en el Instituto Técnico Salesiano (ITS) y comprender cómo la electrónica puede ser utilizada para resolver problemas de sostenibilidad ambiental. La experiencia obtenida subraya la importancia de la organización, la innovación y el trabajo en equipo, aspectos fundamentales para futuros proyectos en cualquier campo de la ingeniería.

## Índice

ITS Villada | 17.

# Repositorio

Los datasheets se pueden encontrar en Documentos > Datasheets Los esquemáticos se pueden encontrar en Diseño > Circuito
El código se puede encontrar en Software > src

_ Repositorio general:
https://github.com/proyectoitsv/SRI_Performance/tree/main
_ Diagramas:
https://github.com/proyectoitsv/SRI_Performance/tree/main/DISE%C3%91O%20SISTEMAS/DIAGRAMAS (https://github.com/proyectoitsv/SRI_Performance/tree/main/DISE%C3%91O%20SISTEMAS/DIAGRAMAS)

_ Circuitos:
https://github.com/proyectoitsv/SRI_Performance/tree/main/DISE%C3%91O/Circuito

_ Logo proyecto:
https://github.com/proyectoitsv/SRI_Performance/tree/main/DISE%C3%91O/Logo

_ Diseño 3D:
https://github.com/proyectoitsv/SRI_Performance/tree/main/DISE%C3%91O/SOPORTES

_ Link interfaz web:
https://v0.app/chat/sistema-de-riego-inteligente-dy5TQQcfZJ3?b=b_B8O9cqEJMls&ref=M2WI 5C#mdcNRNohCfNceRKo45xQfuySscisTNYl (https://v0.app/chat/sistema-de-riego-inteligente-dy5TQQcfZJ3?b=b_B8O9cqEJMls)

_ Software:
https://github.com/proyectoitsv/SRI_Performance/tree/main/Software
ITS Villada | 18.

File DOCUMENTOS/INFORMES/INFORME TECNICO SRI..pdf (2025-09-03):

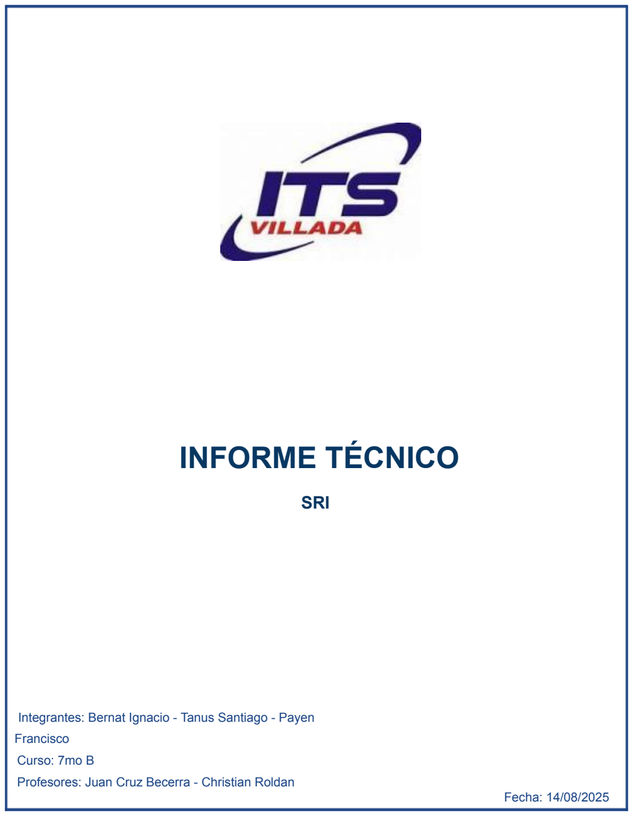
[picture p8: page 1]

# INFORME TÉCNICO

## SRI

Integrantes: Bernat Ignacio - Tanus Santiago - Payen Francisco
Curso: 7mo B
Profesores: Juan Cruz Becerra - Christian Roldan Fecha: 14/08/2025

## Introducción

El presente informe técnico describe el desarrollo e implementación de un Sistema de Riego Inteligente (SRI) orientado a optimizar el consumo de agua en espacios verdes mediante el uso de sensores y control automático. La propuesta integra hardware y software de bajo costo con el fin de ofrecer una solución eficiente y adaptable a diferentes tipos de jardines. Se ha priorizado la automatización basada en datos ambientales en tiempo real, garantizando un riego preciso únicamente cuando las condiciones lo requieren. Este enfoque no solo contribuye al ahorro de recursos hídricos, sino que también reduce el mantenimiento y el tiempo de intervención del usuario, marcando una diferencia significativa frente a métodos de riego tradicionales.

## INDICE

### 1. Resumen Ejecutivo

El dispositivo se trata de un aspersor inteligente capaz de ajustar el riego en función de la humedad del suelo, la temperatura y la época del año. Está dirigido a usuarios particulares que desean cuidar y mantener en óptimas condiciones su césped.

Para su funcionamiento, el sistema utiliza un microcontrolador ESP32 como unidad central, junto con una red de sensores de humedad y temperatura que permiten determinar las zonas que requieren riego y las condiciones ideales para realizarlo. De esta manera, se optimiza el uso del agua, evitando riesgos innecesarios y mejorando la eficiencia en el mantenimiento de jardines y áreas verdes.

El sistema combina sensores de humedad y temperatura con un microcontrolador ESP32 que procesa los datos y decide de manera autónoma cuándo y dónde activar el riego. Gracias a su conectividad WiFi/Bluetooth, el equipo ofrece posibilidades de supervisión y control remoto, ampliando su versatilidad. La integración de un mecanismo móvil en ejes X-Y permite dirigir el riego a zonas específicas, evitando el desperdicio de agua y protegiendo áreas que no requieren hidratación. El diseño se ha planteado con un enfoque modular y escalable, lo que facilita futuras ampliaciones o la incorporación de más aspersores.

### 2. Objetivos del Proyecto

Objetivo General

Diseñar e implementar un sistema de riego inteligente y automatizado que, mediante sensores de
humedad y temperatura controlados por un microcontrolador ESP32, optimice el uso del agua adaptándose a las condiciones específicas del terreno y evitando riesgos innecesarios.

Objetivos Secundarios

- Medir y monitorear en tiempo real la humedad del suelo a través de sensores distribuidos estratégicamente en distintas zonas del jardín.
- Automatizar el riego sectorizado, activando el aspersor únicamente en áreas con déficit hídrico.
- Reducir el consumo de agua y los costos operativos, minimizando el desperdicio del recurso.
- Implementar una interfaz sencilla para el monitoreo remoto, que permita visualizar datos de humedad y el estado del sistema en tiempo real.

### 3. Especificaciones del sistema

Requerimientos funcionales: El sistema debe realizar mediciones precisas y continuas de humedad y temperatura, evaluar la necesidad de riego, y ejecutar la activación de la bomba y el movimiento del aspersor según la ubicación de las zonas secas.

Requerimientos no funcionales: Se busca un bajo consumo energético, integración estética con el entorno y facilidad para ampliar el sistema a múltiples nodos.

Limitaciones: El alcance del sistema está condicionado por la disposición física de los sensores y la cantidad de entradas analógicas disponibles. También se contempla la necesidad de sensores más robustos para una versión comercial duradera.

### 4. Diseño de Hardware

El hardware se estructura en torno al ESP32, elegido por su potencia de cálculo, conectividad y capacidad de manejar periféricos diversos. Los sensores HL-69 y LM35 realizan la captura de datos ambientales. La orientación del aspersor se consigue mediante un servo MG995 para ajustes finos y un motor paso a paso NEMA 17 con driver A4988 para desplazamientos amplios en ejes X-Y.

El sistema cuenta con una bomba de agua de 12 V, tuberías y cableado subterráneo para preservar la estética del jardín. El diagrama de estados y el consumo eléctrico se han considerado para asegurar un funcionamiento autónomo y confiable, con mecanismos de seguridad como corte por sobrecorriente.

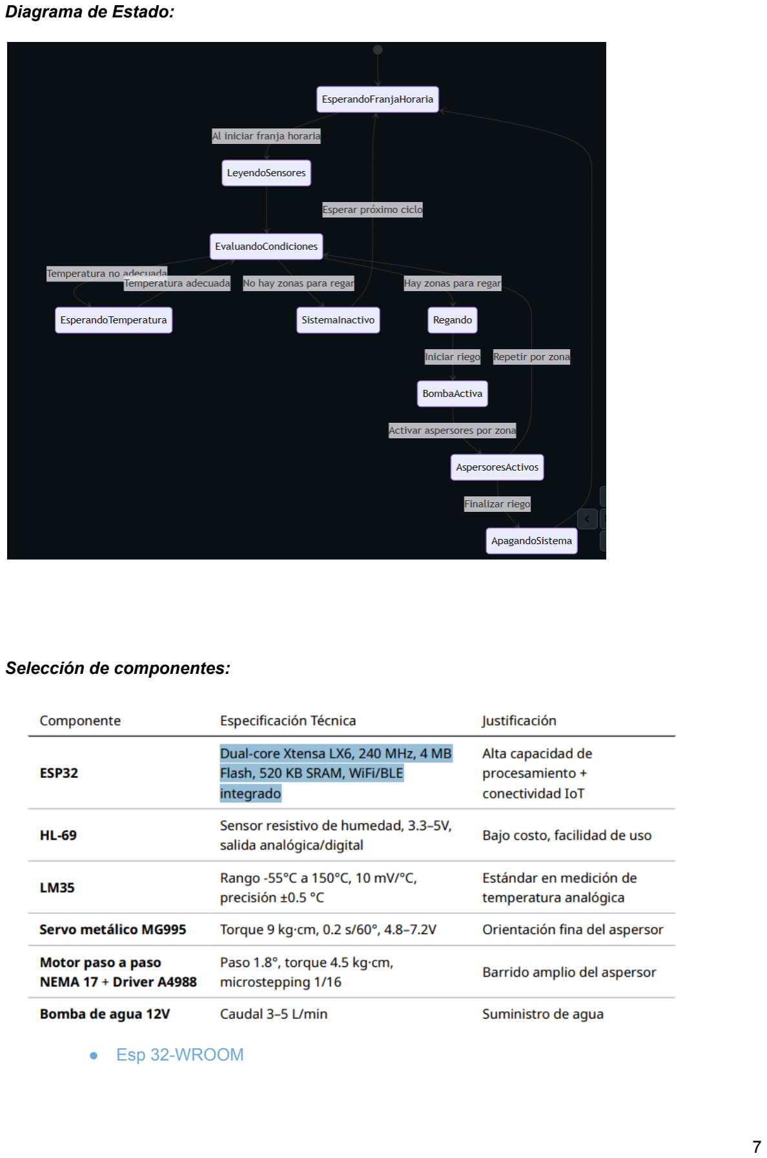
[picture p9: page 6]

Diagrama de Estado:

Selección de componentes:

- Esp 32-WROOM

Consumo del sistema:
ESP32: 160 mA en operación.
Servo: 0,5 - 0,7 A pico.
Motor paso a paso: 1.2 -- 1.5 A por fase. Bomba: 0,5 - 0,7 A.
Tensión nominal: - Bomba: 12V DC.
- ESP 32 y Placa de acondicionamiento: 3,3V DC.
- Sensores: 5V DC.

En cuanto el diseño de los esquemáticos y pcb correspondientes, estos se encuentran en desarrollo y serán presentados posteriormente en el informe final del presente proyecto.

### 5. Diseño de firmware

Arquitectura del sistema:

El firmware se divide en módulos:

- Sensado: adquisición de datos desde los sensores de humedad y temperatura.
- Decisión: procesamiento de datos y determinación de riego en el ESP32.
- Control: activación de motores, bomba y orientación del aspersor.
- Interfaz: visualización en LCD y comunicación por WiFi/Bluetooth.

Se utilizan diagramas de flujo, casos de uso y pseudocódigo como base para la programación definitiva. El código final incorporará mecanismos de seguridad adicionales y optimización del consumo de recursos.

Diagramas del sistema:

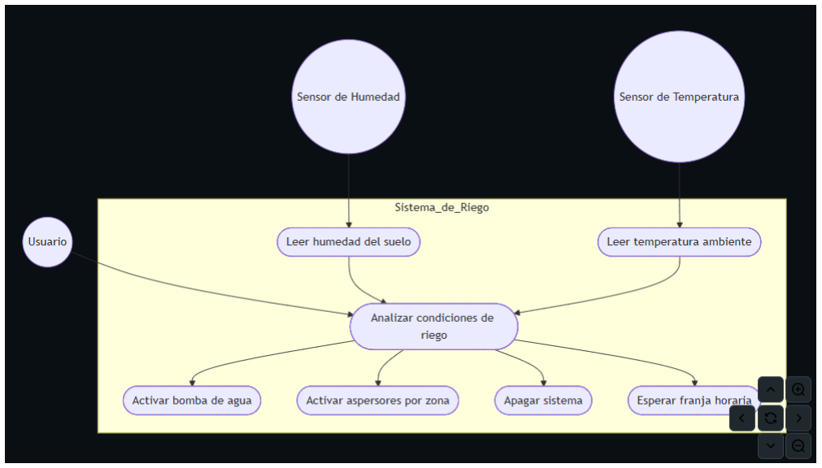
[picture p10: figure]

Diagrama de casos de uso

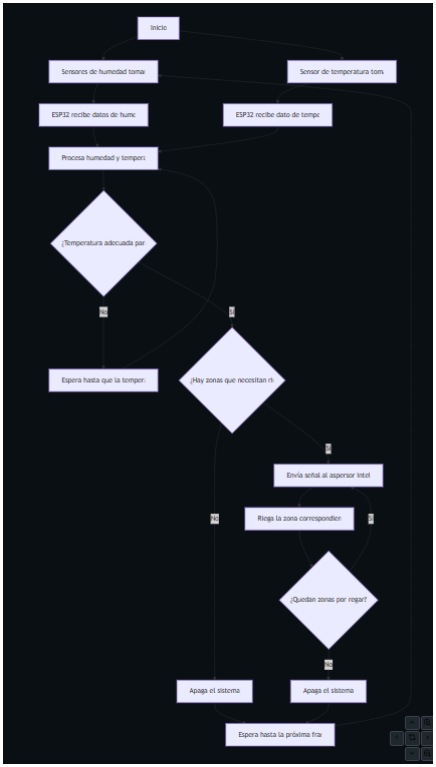
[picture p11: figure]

Diagrama de flujo

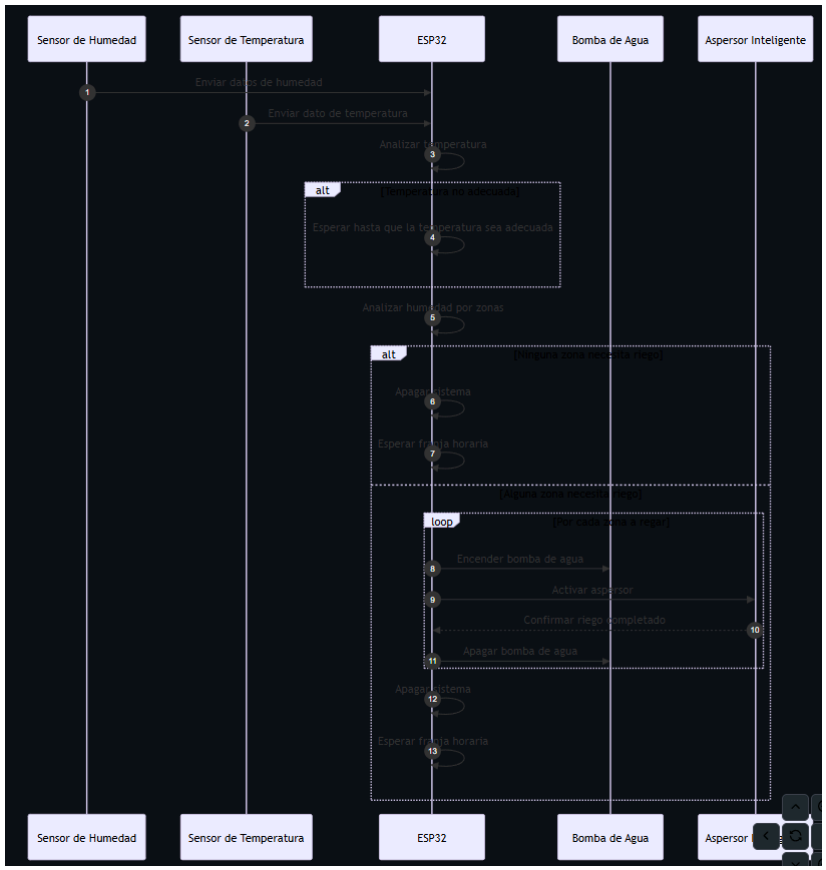
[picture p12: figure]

Diagrama de secuencia

Pseudocódigo:

A continuación se presenta un pseudo código el cual tendrá varias similitudes con el código definitivo del sistema de riego. El código final se encuentra en desarrollo. Al pseudocódigo se le deberán agregar definiciones de variables, contenido a las funciones y líneas extra para agregar mecanismos de protección del sistema así como preferencias de los desarrolladores. También el código definitivo será a su vez una versión optimizada de todos los pseudocódigos desarrollados durante el proceso.

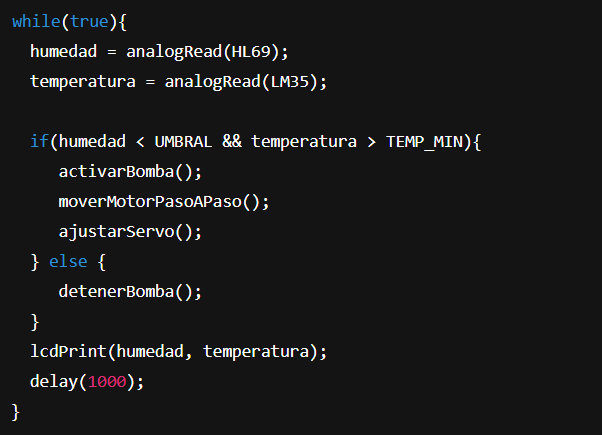
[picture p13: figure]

Controladores y Periféricos

- ADC de 12 bits para sensores analógicos.
- GPIOs PWM para servo.
- Driver A4988 controlado por el ESP32.

Manejo de Errores y Seguridad

- Corte automático en caso de sobrecorriente de bomba.
- Desconexión si humedad > 90% (riesgo de cortocircuito y fallas en el sistema).

### 6. Pruebas y validación

Las pruebas se enfocan en verificar la exactitud de los sensores, la respuesta del sistema ante diferentes condiciones climáticas, y la eficiencia en el uso del agua. Durante esta etapa, se registran ajustes de calibración, tiempos de respuesta y posibles fallos en la comunicación o alimentación.

### 7. Mejoras a futuro

Se proyecta el desarrollo de un servidor externo para respaldo de datos, así como una interfaz web avanzada que permita modificar parámetros, habilitar/deshabilitar el sistema y consultar registros históricos de temperatura y humedad. También se considera la integración con pronósticos meteorológicos para anticipar y ajustar los ciclos de riego.

### 8. Hojas de datos

Datasheets:

LM35: https://www.alldatasheet.com/datasheet-pdf/view/517588/TI1/LM35.html

HL-69/YL-69: https://es.scribd.com/document/631786081/Soil-Moisture-Sensor

LF347: https://www.alldatasheet.es/datasheet-pdf/view/530067/TI/LF347.html

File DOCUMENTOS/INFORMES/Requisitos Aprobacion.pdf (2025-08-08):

1

## PROYECTO INTEGRADOR REQUISITOS DE APROBACIÓN

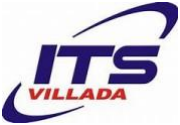
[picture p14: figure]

INSTITUTO TECNICO SALESIANO VILLADA

Alumnos:

- Santiago Tanus - Ignacio Bernat

Profesores:

- Federico Ferraro - Matias Schulthess

Córdoba, Córdoba, Argentina

Fecha: 08/08/2025

2

Los requisitos mínimos de aprobación para el proyecto integrador de sistema de riego inteligente (SRI) orientado al uso domiciliario Tiene que contar con el funcionamiento de un ESP32, sensores de humedad HL-95, un sensor de temperatura DHT11/22, un servomotor y un motor paso a paso que controlan el acimut y la elevación del aspersor, y una bomba de agua activada con un rele. Debe contar con un limite de rangos, y la posibilidad de un sistema integrado para prender y apagar el sistema mediante un interruptor.

Como requisitos extra, los datos deben ser visualizados y configurados mediante una interfaz web interna del ESP32. función de parámetros agronómicos como la Capacidad de Campo y Punto de Marchitez Permanente, minimizando el consumo de agua y maximizando la eficiencia de riego. Automatizar el sistema para que funcione sin necesidad de una PC conectada.

El sistema

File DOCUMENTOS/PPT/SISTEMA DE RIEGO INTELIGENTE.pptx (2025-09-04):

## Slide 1

Sistema de Riego Inteligente

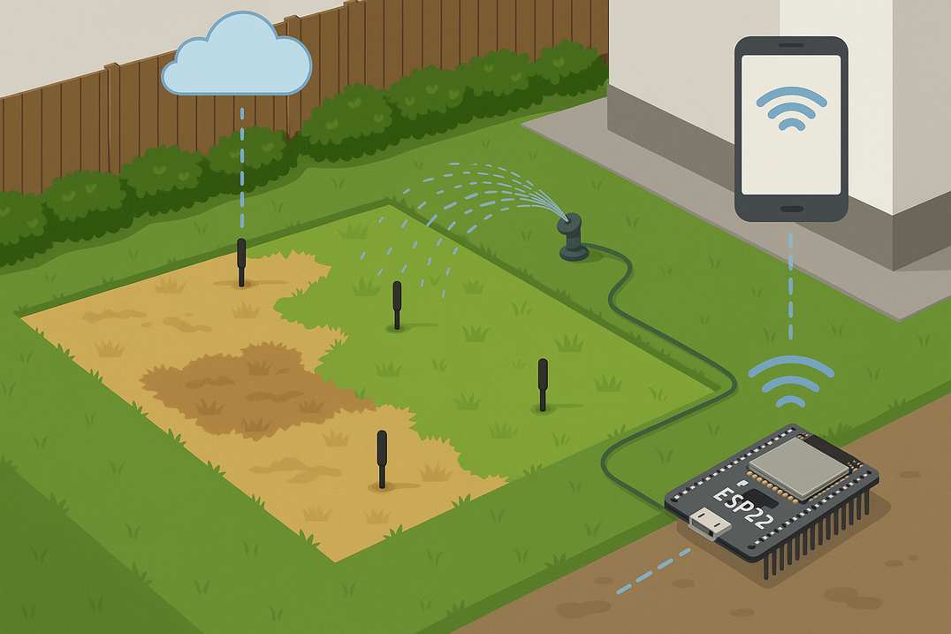
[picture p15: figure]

SRI PERFORMANCE

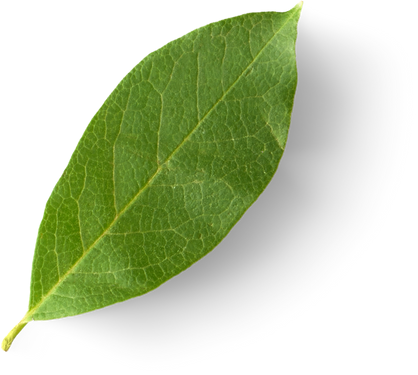
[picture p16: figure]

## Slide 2

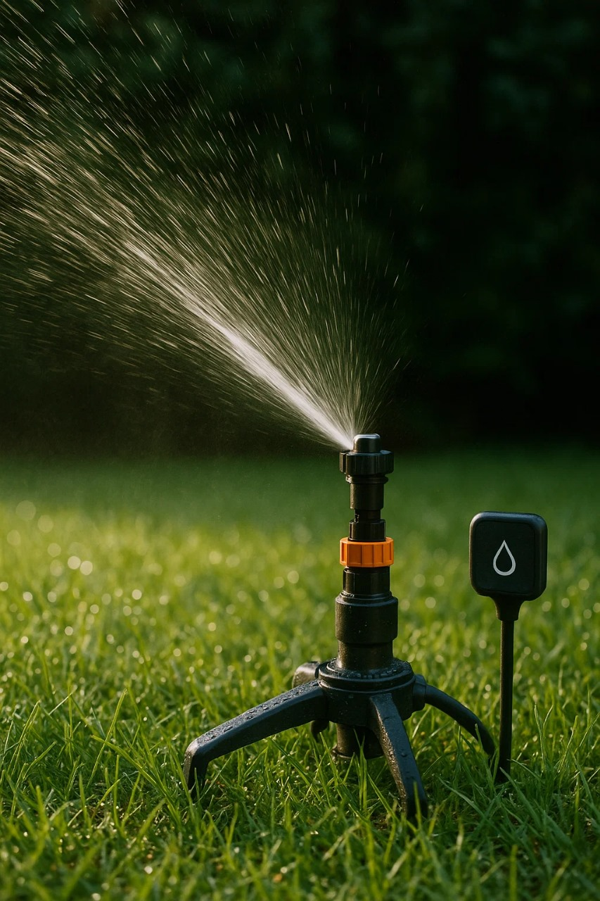
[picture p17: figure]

Objetivo del Proyecto

Solucionar el problema del consumo de agua excesivo a través de un sistema de riego inteligente.

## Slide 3

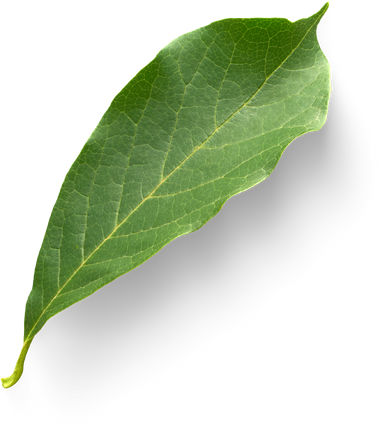
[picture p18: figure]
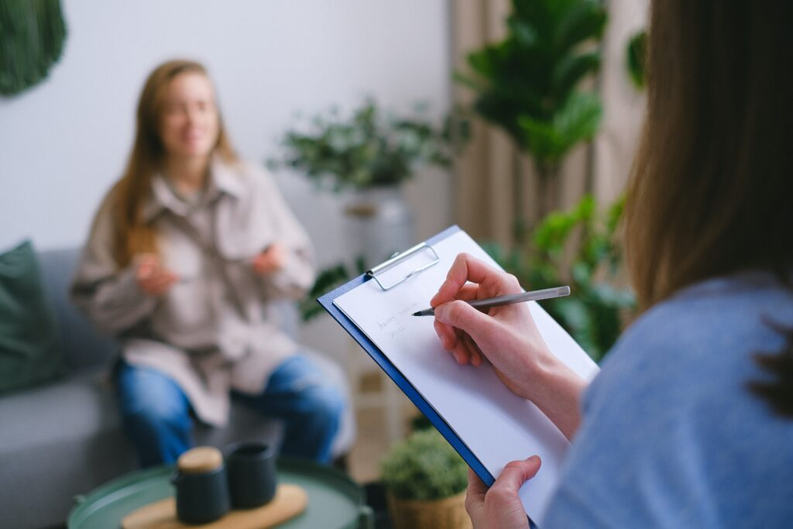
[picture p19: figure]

Encuesta a Usuarios

60% Estaban dispuestos a mejorar su sistema
33% No querian
7% Lo consideraria dependiendo el precio

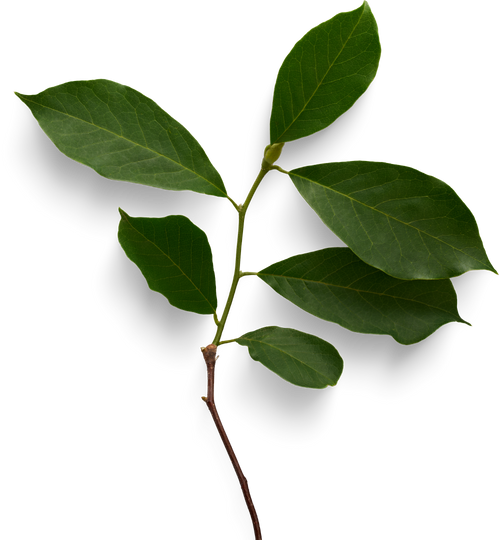
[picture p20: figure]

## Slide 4

Estadísticas a Escala Nacional

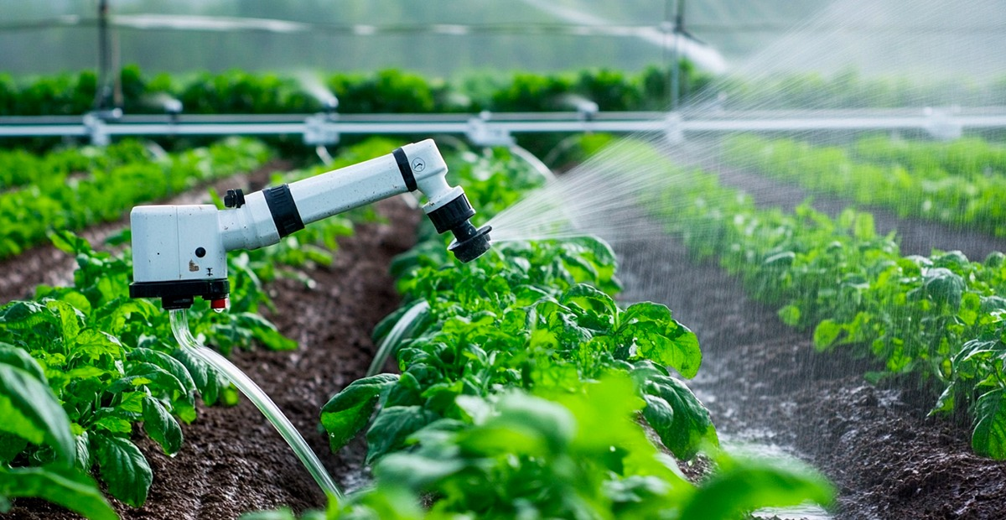
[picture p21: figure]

50% del consumo de agua se dedica al riego de cesped en los meses de primavera y verano

6-8 Litros de agua por M²

Eficiencia de sistemas de riego actuales 75-85%

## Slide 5

Problematicas

  - Riego excesivo o insuficiente
  - Falta de sectorización
  - Exceso o falta en la dosificación de fertilizante

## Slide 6

Producto a Desarrollar

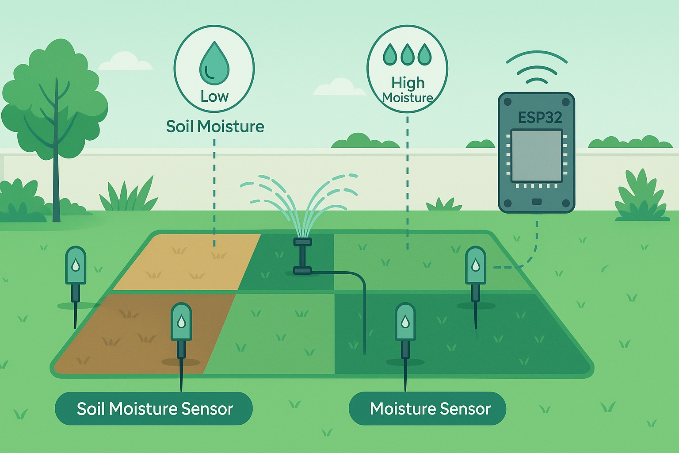
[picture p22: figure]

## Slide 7

Beneficios del Sistema

Un ahorro de 10000l por mes, cada 250m²

Un sistema facil de instalar, barato y ecológico.

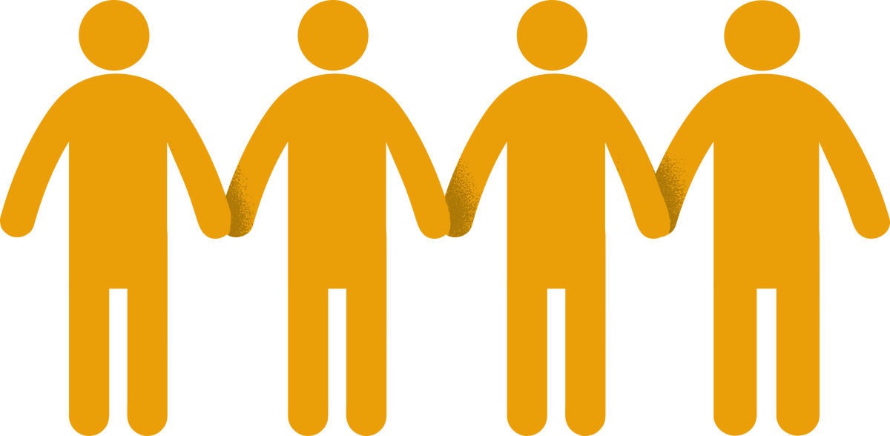
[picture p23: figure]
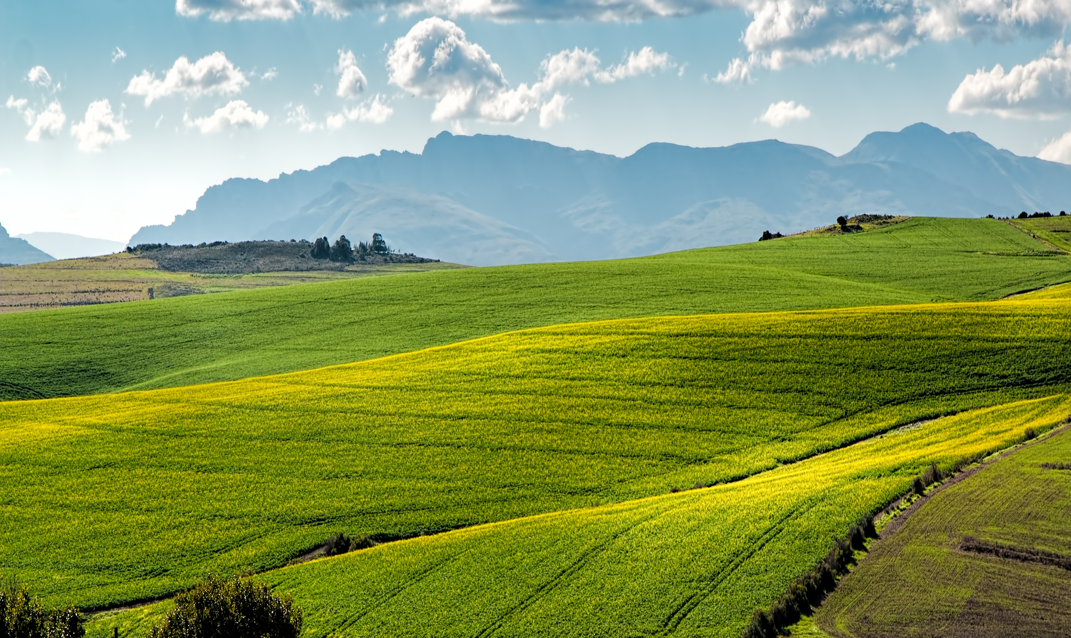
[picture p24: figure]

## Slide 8

Gracias por su atencion

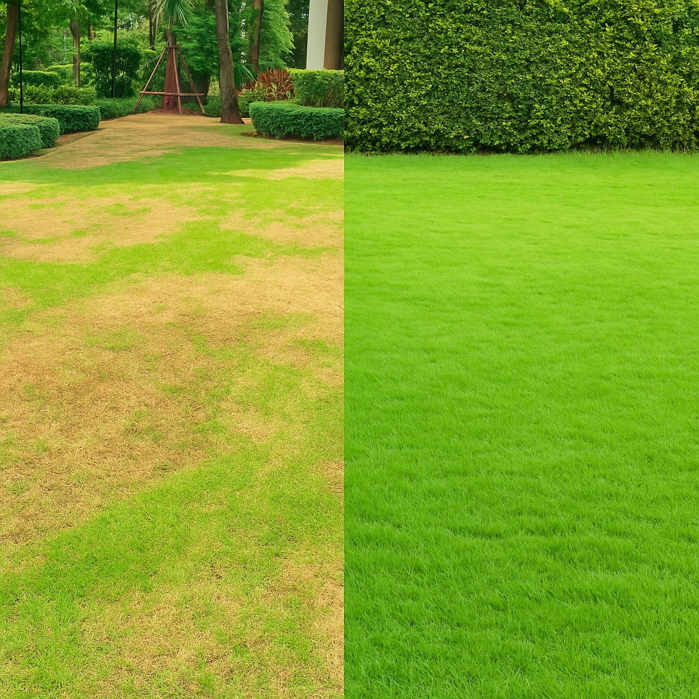
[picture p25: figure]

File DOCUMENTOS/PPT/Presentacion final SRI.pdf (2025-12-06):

# •SRI PERFORMANCE•


# DISEÑO

# Investigación: La


# Problemática del Césped Saludable

### Mantenimiento del Césped

Para un césped saludable, es crucial

entender sus necesidades de agua,

nutrientes y luz solar. Un rie adecuado es

fundamental para su crecimiento y

resistencia.

### Ventajas de Nuestro Sistema

Nuestro sistema supera a los métodos tradicionales al ofrecer un análisis en tiempo real de las condiciones del suelo, optimizando el riego y reduciendo el desperdicio.

### Variables Clave

Consideramos variables como el tipo de suelo, la evapotranspiración, la capacidad de campo y el punto de marchitez permanente para un cuidado personalizado.

# ¿Qué impacto tiene?

# Solución elegida


# FUNCIONAMIENTO


# PROTOTIPO SRI


# Futuras Implementaciones…

# APP - Interfaz de usuario


# Potenciales Socios Comerciales



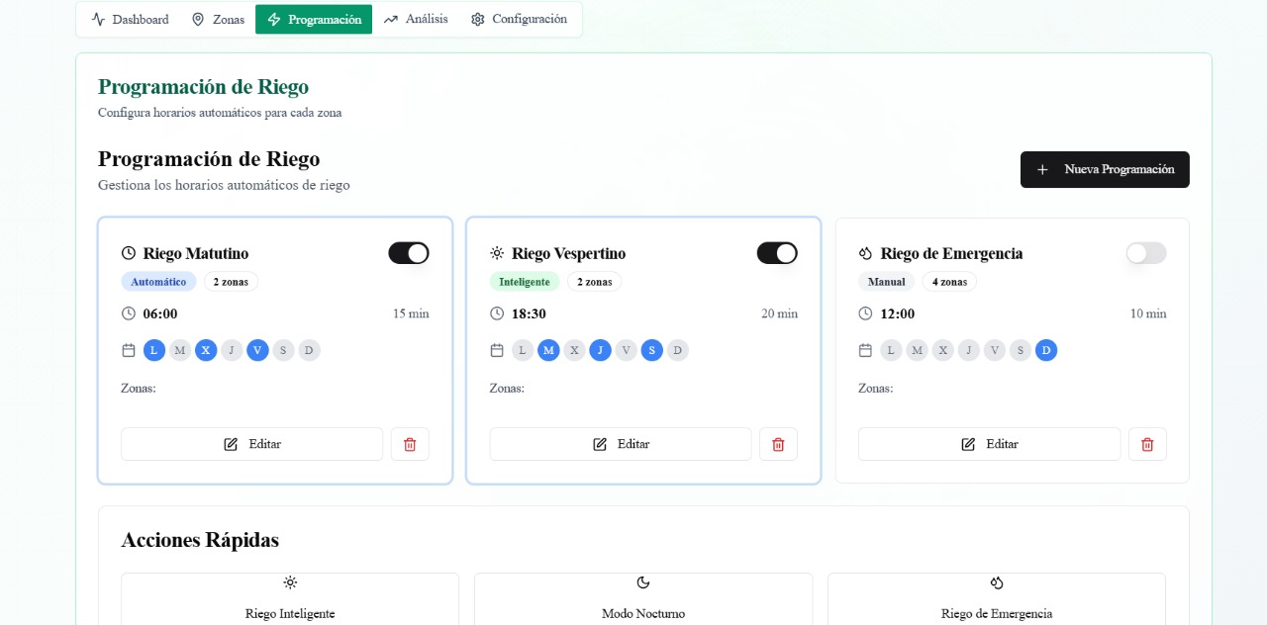
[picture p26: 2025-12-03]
INTERFAZ GRAFICA/IMAGEN_INTERFAZ6.jpg

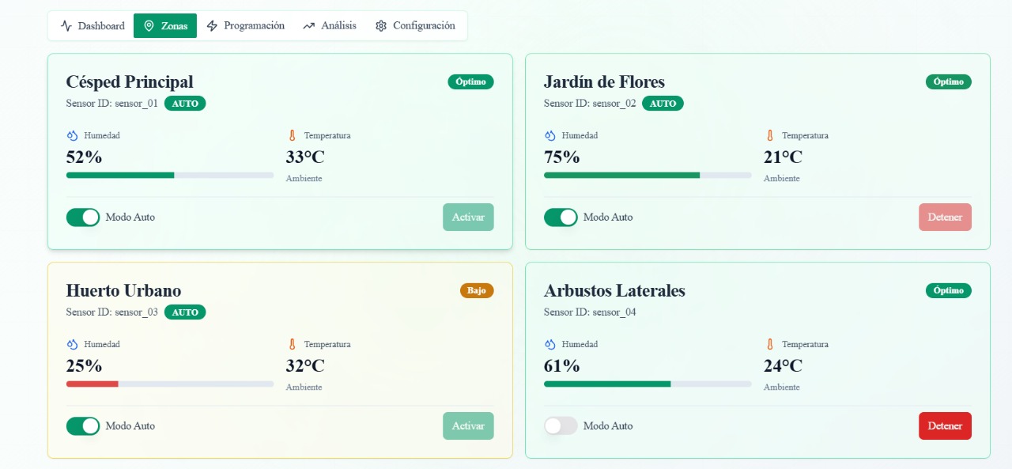
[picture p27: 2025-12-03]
INTERFAZ GRAFICA/IMAGEN_INTERFAZ5.jpg

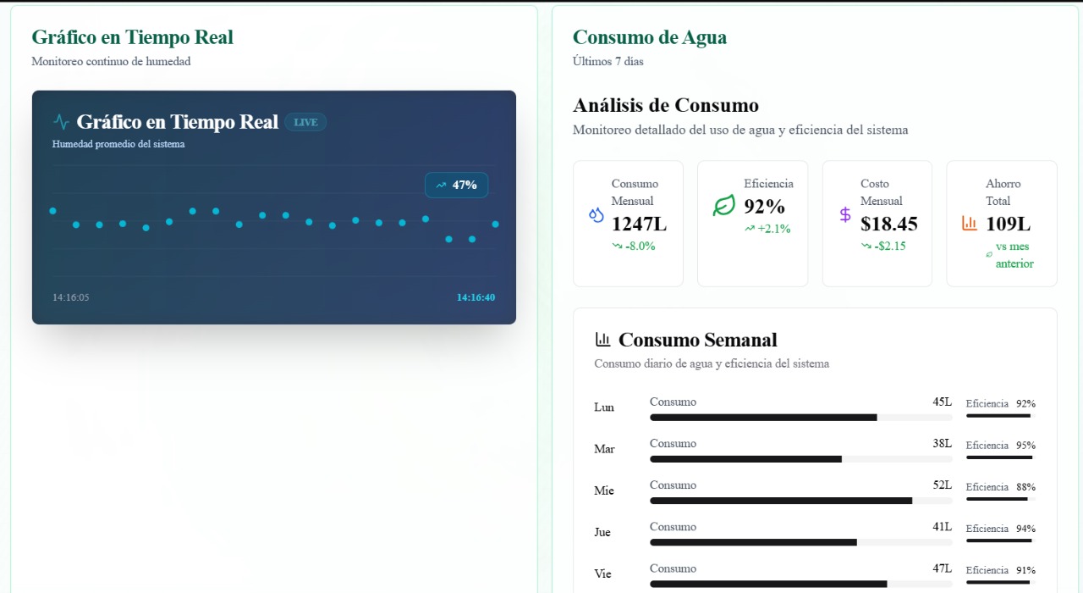
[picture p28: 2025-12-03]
INTERFAZ GRAFICA/IMAGEN_INTERFAZ3.jpg

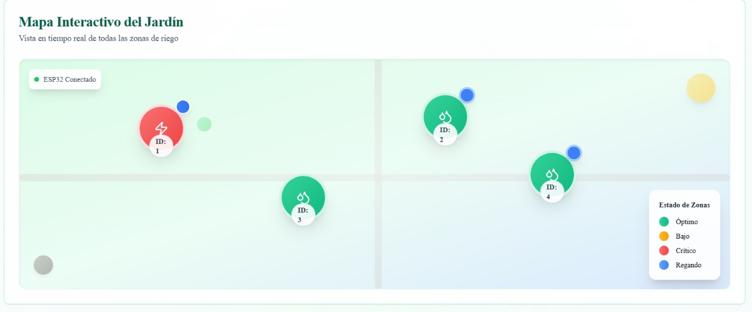
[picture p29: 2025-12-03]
INTERFAZ GRAFICA/IMAGEN_INTERFAZ2.jpg

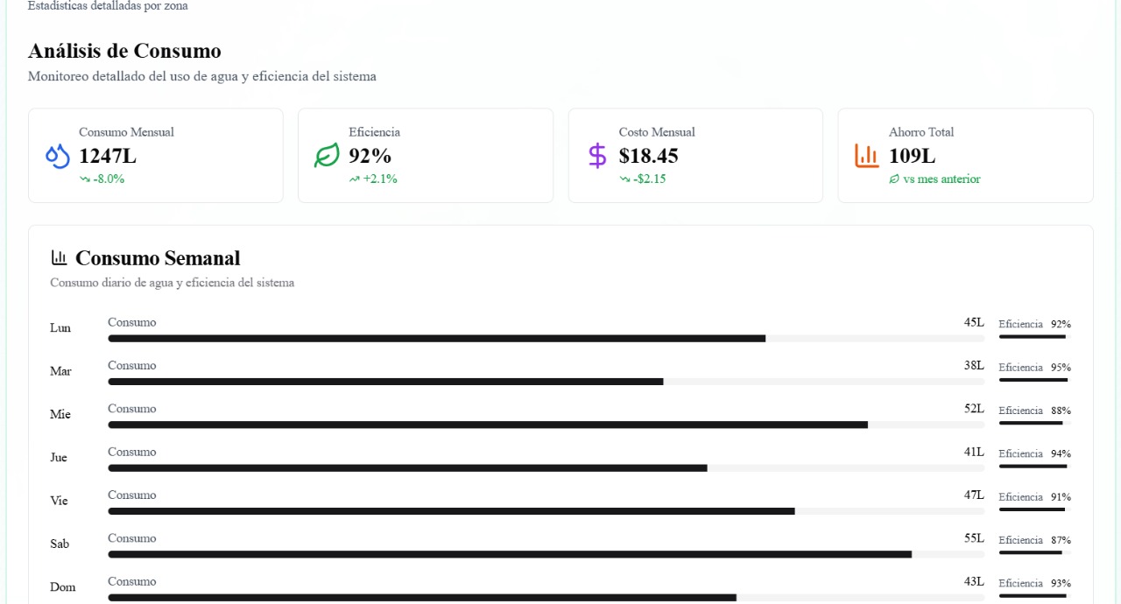
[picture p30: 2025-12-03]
INTERFAZ GRAFICA/IMAGEN_INTERFAZ7.jpg

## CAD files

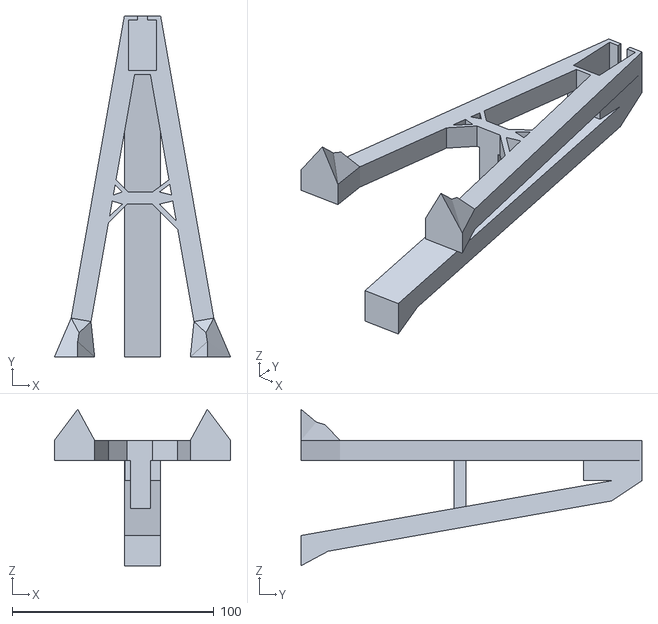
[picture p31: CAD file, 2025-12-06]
DISEÑO/SOPORTES/Torre.STL
87.4 x 169.0 x 77.6

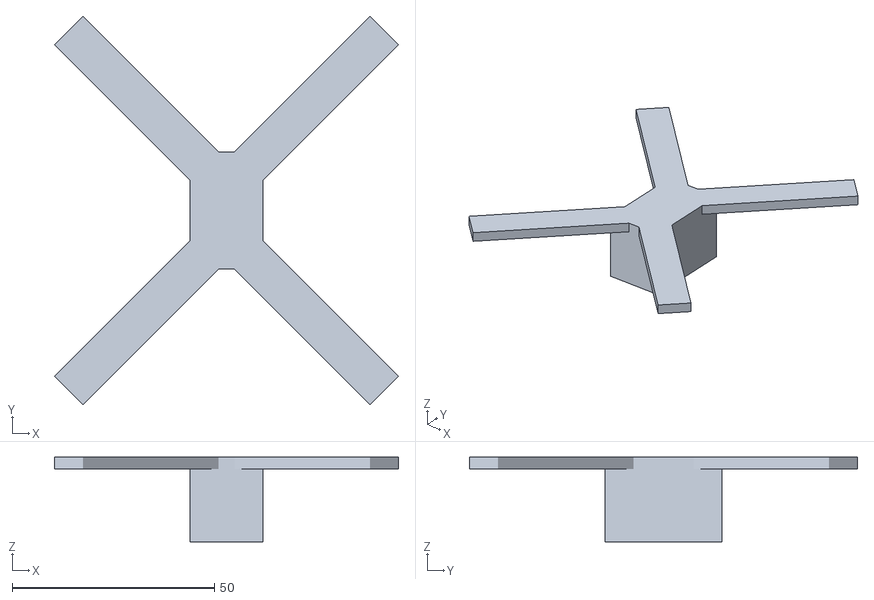
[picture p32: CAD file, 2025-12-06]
DISEÑO/SOPORTES/SoporteServoBase.STL
85.1 x 96.1 x 21.0

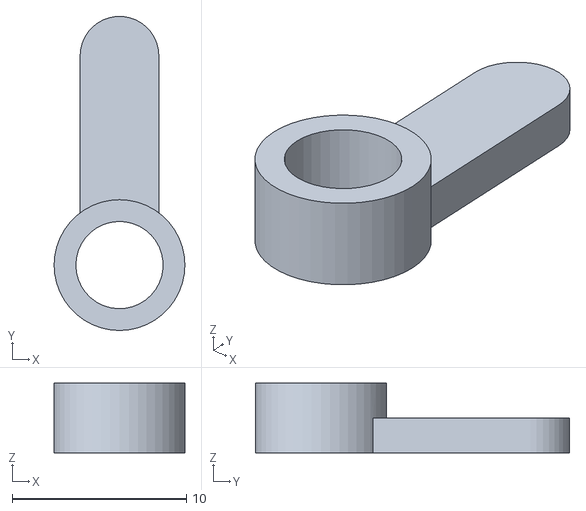
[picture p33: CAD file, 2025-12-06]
DISEÑO/SOPORTES/patamejorada.STL
7.50 x 18.0 x 4.00

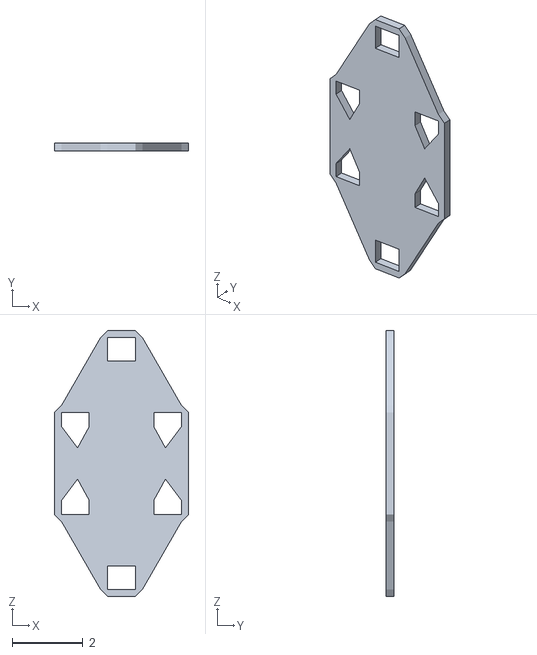
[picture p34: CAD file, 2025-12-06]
DISEÑO/SOPORTES/BaseDeTorres.stl
3.79 x 0.236 x 7.52

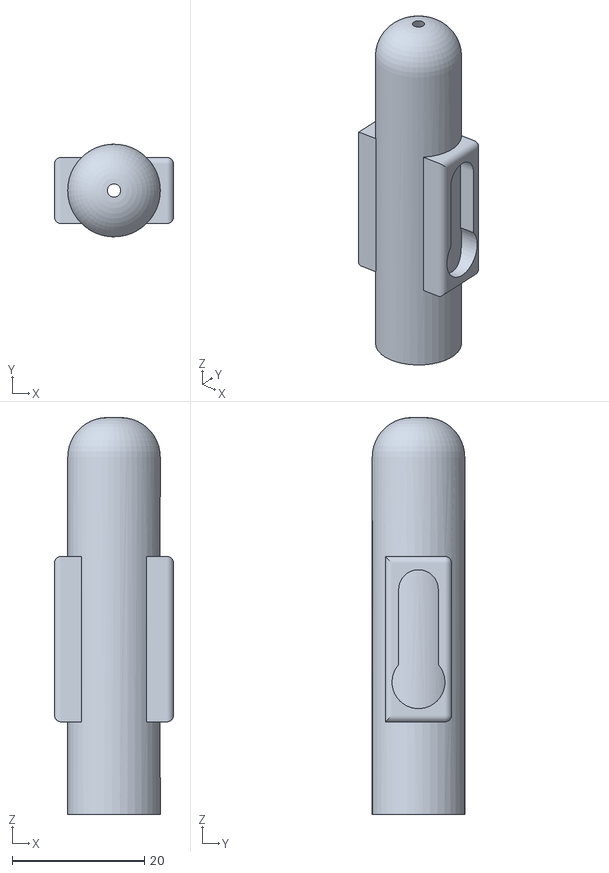
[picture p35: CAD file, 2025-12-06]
DISEÑO/SOPORTES/REDUCTOReducido.STL
18.0 x 14.0 x 60.0

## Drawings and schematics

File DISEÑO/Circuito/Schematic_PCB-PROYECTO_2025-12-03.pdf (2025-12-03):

## ESP32 WROOM-32

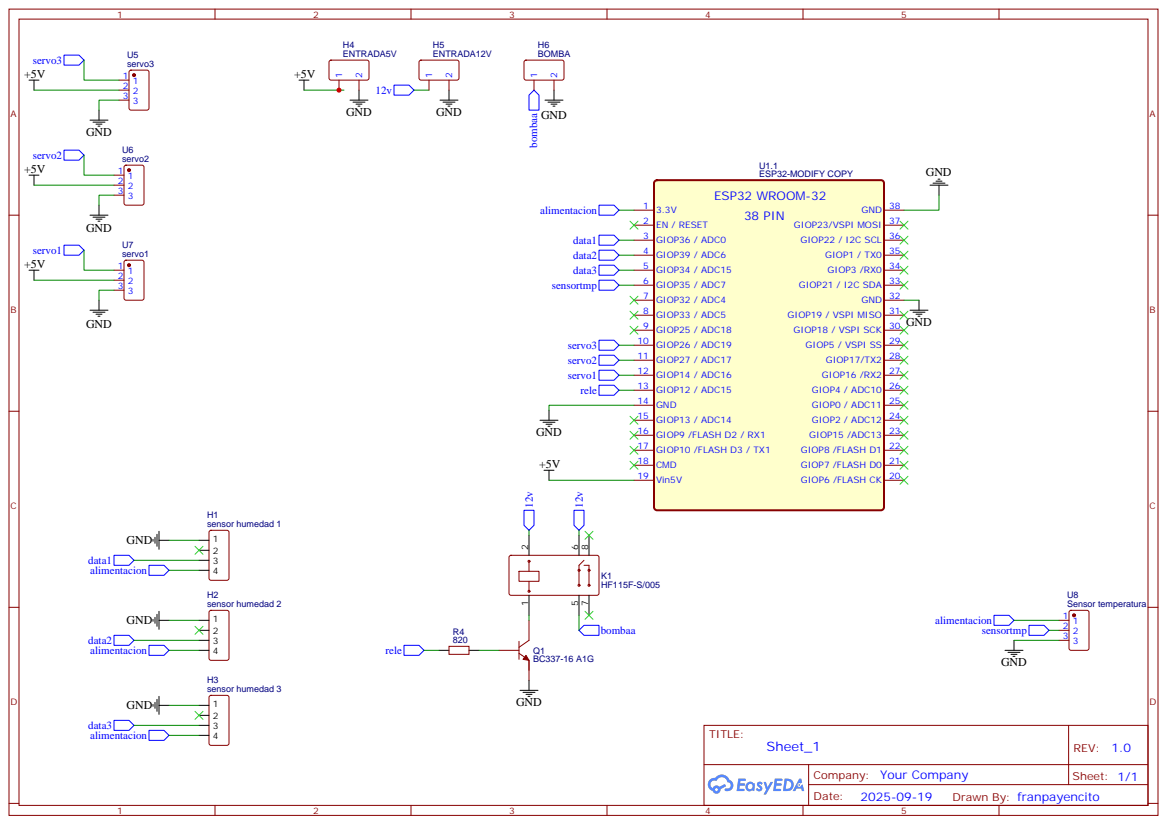
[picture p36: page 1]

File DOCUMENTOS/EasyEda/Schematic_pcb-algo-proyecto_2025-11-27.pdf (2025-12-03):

## ESP32 WROOM-32

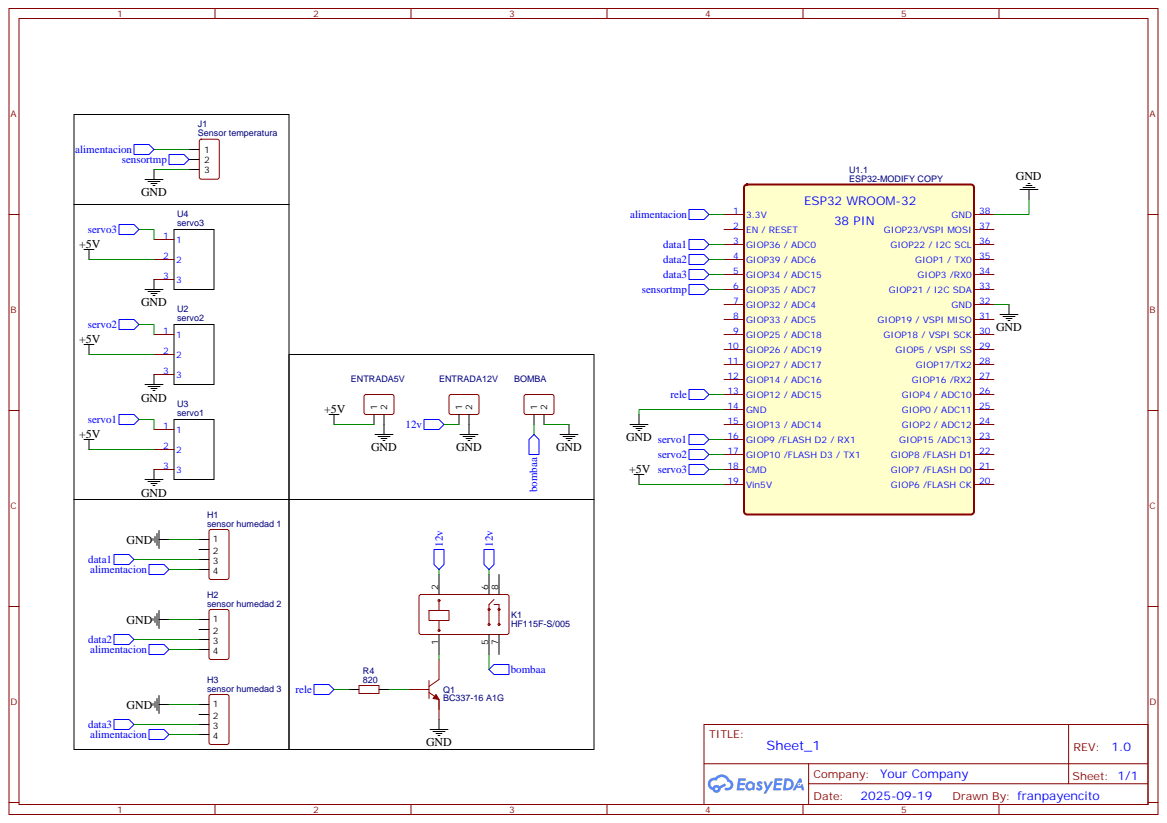
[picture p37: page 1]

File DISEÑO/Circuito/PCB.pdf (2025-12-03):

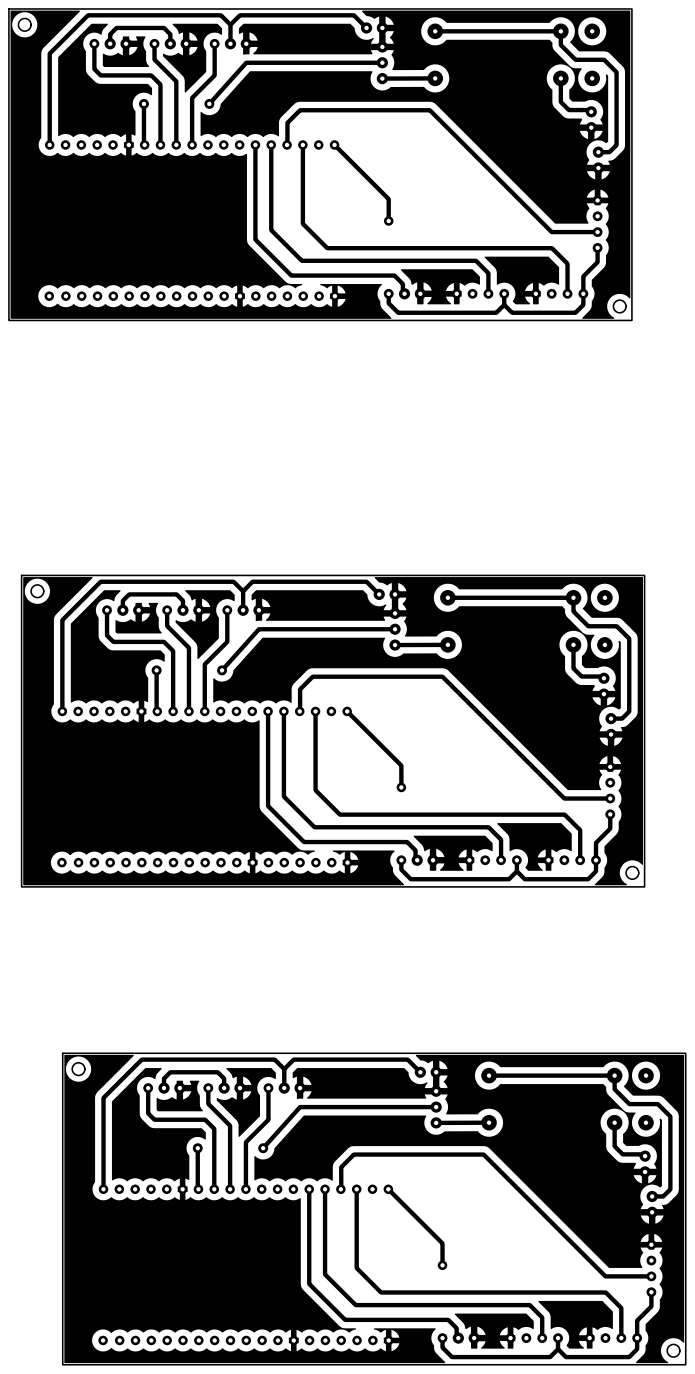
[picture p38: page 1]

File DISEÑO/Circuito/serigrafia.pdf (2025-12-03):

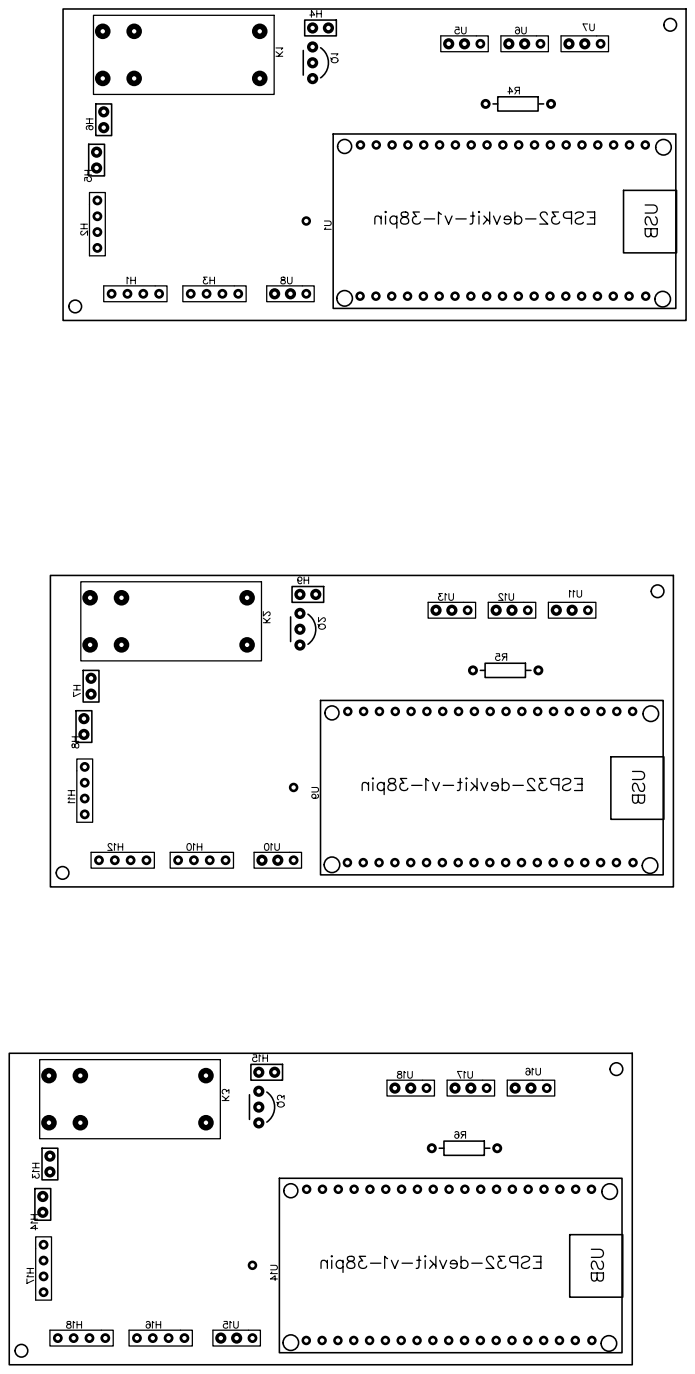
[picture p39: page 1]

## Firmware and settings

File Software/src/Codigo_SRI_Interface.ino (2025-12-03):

#include <Arduino.h>
#include <DHT22.h>
#include <WiFi.h>
#include <WebServer.h>
#include <time.h>

// ------------------- Definiciones -------------------
#define Sens_HUM1 36
#define Sens_HUM2 39
#define Sens_HUM3 34
#define SERVO_1 14
#define SERVO_2 27
#define SERVO_3 26
#define INDI_LED 23 
#define TEMP 0
#define BOMBA 12

// Configuración PWM
const int PWM_CHANNEL_SERVO_1 = 0;
const int PWM_CHANNEL_SERVO_2 = 1;
const int PWM_CHANNEL_SERVO_3 = 2;

const int PWM_FREQ = 50;      
const int PWM_RESOLUTION = 16;  
const int MAX_DUTY_CYCLE = (int)(pow(2, PWM_RESOLUTION) - 1);

const int LED_OUTPUT_PIN_1 = SERVO_1;   // Usamos pin 18 para PWM (separado del LED indicador)
const int LED_OUTPUT_PIN_2 = SERVO_2;   // Usamos pin 18 para PWM (separado del LED indicador)
const int LED_OUTPUT_PIN_3 = SERVO_3;   // Usamos pin 18 para PWM (separado del LED indicador)

const int DELAY_MS = 4;          // Delay para fade9

// WiFi
const char* ssid       = "BERNAT-2.4G-52tW";//"Electronica_7moB";// 
const char* password   =  "Valentina_2022*";//"proyecto7B!";// 

// NTP
const long gmtOffset_sec = -10800;  
const int daylightOffset_sec = 0;
const char* ntpServer = "pool.ntp.org";

// Variables globales
uint16_t HUM_1 = 0;
uint16_t HUM_2 = 0;
uint16_t HUM_3 = 0;
float t = 0;
bool franja_OK = 0;

uint16_t PWM_value_1 = 8200;   // Valor inicial PWM
uint16_t PWM_value_2 = 4875;   // Valor inicial PWM
uint16_t PWM_value_3 = 1750;   // Valor inicial PWM

bool riego1_activo = false;
bool riego2_activo = false;
bool riego3_activo = false; 

DHT22 dht22(TEMP); 
WebServer server(80);

// Funciones Riego
void riego_Sector1(void);
void riego_Sector2(void);
void riego_Sector3(void);

// ------------------- Setup -------------------
void setup() {
  Serial.begin(9600);
  pinMode(TEMP, INPUT);
  pinMode(INDI_LED, OUTPUT);
  pinMode(BOMBA, OUTPUT);

  // Conexión WiFi
  WiFi.begin(ssid, password);
  while (WiFi.status() != WL_CONNECTED) {
    delay(500);
    Serial.print(".");
  }
  Serial.println("\nConectado a WiFi");
  Serial.println("IP local: " + WiFi.localIP().toString());

  // Configuración NTP
  configTime(gmtOffset_sec, daylightOffset_sec, ntpServer);

  // Servidor web
  server.on("/", handleRoot);
  server.on("/datos", handleDatos);
  server.begin();

  // Configuración PWM
  ledcSetup(PWM_CHANNEL_SERVO_1, PWM_FREQ, PWM_RESOLUTION);
  ledcAttachPin(LED_OUTPUT_PIN_1, PWM_CHANNEL_SERVO_1);

  ledcSetup(PWM_CHANNEL_SERVO_2, PWM_FREQ, PWM_RESOLUTION);
  ledcAttachPin(LED_OUTPUT_PIN_2, PWM_CHANNEL_SERVO_2);

  ledcSetup(PWM_CHANNEL_SERVO_3, PWM_FREQ, PWM_RESOLUTION);
  ledcAttachPin(LED_OUTPUT_PIN_3, PWM_CHANNEL_SERVO_3);
}

// ------------------- Loop -------------------
void loop() {
  server.handleClient();
  if(franja_OK == true){
      get_data();
      riego_Sector1();
      riego_Sector2();
      riego_Sector3();
  } 
}

// ------------------- Funciones auxiliares -------------------
int getSoil_moisture(int num){
  uint16_t hum = analogRead(num);
  int S_HumD = (-0.0367 * hum) + 150.2865;
  return constrain(S_HumD, 0, 100);
}

void get_data(void){
  t = dht22.getTemperature();
  HUM_1 = getSoil_moisture(Sens_HUM1);
  HUM_2 = getSoil_moisture(Sens_HUM2);
  HUM_3 = getSoil_moisture(Sens_HUM3);  
  if (dht22.getLastError() != dht22.OK) {
    Serial.print("Error DHT22: ");
    Serial.println(dht22.getLastError()); 
  }
}

void handleRoot() {
  String html = R"rawliteral(
    <!DOCTYPE html><html><head><meta charset='UTF-8'><title>Datos SRI</title>
    <script>
      function actualizarDatos() {
        fetch('/datos')
          .then(response => response.json())
          .then(data => {
            document.getElementById('temp').innerText = data.temperatura + ' °C';
            document.getElementById('hum1').innerText = data.hum1 + ' %';
            document.getElementById('hum2').innerText = data.hum2 + ' %';
            document.getElementById('hum3').innerText = data.hum3 + ' %';
            document.getElementById('franja').innerText = data.franja ? 'ACTIVA' : 'INACTIVA';
          });
      }
      setInterval(actualizarDatos, 2000);
    </script></head><body>
    <h2>Proyecto SRI - Datos en tiempo real</h2>
    <p>Temperatura: <span id='temp'>--</span></p>
    <p>Humedad 1: <span id='hum1'>--</span></p>
    <p>Humedad 2: <span id='hum2'>--</span></p>
    <p>Humedad 3: <span id='hum3'>--</span></p>
    <p>Franja horaria: <span id='franja'>--</span></p>
    </body></html>
  )rawliteral";

  server.send(200, "text/html", html);
}

void handleDatos() {
  get_data(); 

  struct tm timeinfo;
  if (getLocalTime(&timeinfo)) {
    int hora = timeinfo.tm_hour;
    int minuto = timeinfo.tm_min;
    franja_OK = ((hora == 5 && minuto >= 30) || (hora >= 6 && hora <= 9) || 
                 (hora == 9 && minuto >= 30) || (hora >= 22 && hora <= 24) ||
                 (hora == 0 ));    
    digitalWrite(INDI_LED, franja_OK ? HIGH : LOW);
  }

  String json = "{";
  json += "\"temperatura\":" + String(t) + ",";
  json += "\"hum1\":" + String(HUM_1) + ",";
  json += "\"hum2\":" + String(HUM_2) + ",";
  json += "\"hum3\":" + String(HUM_3) + ",";
  json += "\"franja\":" + String(franja_OK ? "true" : "false");
  json += "}";

  server.send(200, "application/json", json);
}
void riego_Sector1(void){
  // Código para riego del Sector 1
  if(t >= 10 && t <= 25 && HUM_1 < 60 ){
    ledcWrite(PWM_CHANNEL_SERVO_1, 8200);
    ledcWrite(PWM_CHANNEL_SERVO_2, 1750);
    ledcWrite(PWM_CHANNEL_SERVO_3, 1750);
    digitalWrite(BOMBA, HIGH); // Activar riego

    riego1_activo = true;

    while (HUM_1 < 80)
    {
      server.handleClient();
      get_data();
    }
    riego1_activo = false;
    digitalWrite(BOMBA, LOW); // Desactivar riego
    
  }
}
void riego_Sector2(void){
  // Código para riego del Sector 2
  if(t >= 10 && t <= 25 && HUM_2 < 60 ){
    ledcWrite(PWM_CHANNEL_SERVO_1, 6388);
    ledcWrite(PWM_CHANNEL_SERVO_2, PWM_value_2);
    ledcWrite(PWM_CHANNEL_SERVO_3, PWM_value_2);
    digitalWrite(BOMBA, HIGH); // Activar riego

    riego2_activo = true;

    while (HUM_2 < 80)
    {
      server.handleClient();
      get_data();
    }
    riego2_activo = false;
    digitalWrite(BOMBA, LOW); // Desactivar riego
    
  }
}
void riego_Sector3(void){
  // Código para riego del Sector 3
  if(t >= 10 && t <= 25 && HUM_3 < 60 ){
    ledcWrite(PWM_CHANNEL_SERVO_1, 4782);
    ledcWrite(PWM_CHANNEL_SERVO_2, PWM_value_3);
    ledcWrite(PWM_CHANNEL_SERVO_3, PWM_value_3);
    digitalWrite(BOMBA, HIGH); // Activar riego

    riego3_activo = true;

    while (HUM_3 < 80)
    {
      server.handleClient();
      get_data();
    }
    riego3_activo = false;
    digitalWrite(BOMBA, LOW); // Desactivar riego
    
  }
}

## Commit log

2025-06-05 se movieron archivos a la carpeta doc. se cambio la extension de los diagramas a mmd
2025-06-06 se cambiaron los diagramas a .mmd por error de visualizacion
2025-08-08 Requisitos de aprobacion
    se creo un archi donde se mencionan los requisitos minimos de aprobacion dispuestos entre alumno/profesor
2025-09-03 Create INFORME TECNICO SRI..pdf
    se sube el informe tecnico del proyecto
2025-11-13 Initialize PlatformIO project structure for ESP32
    Added PlatformIO configuration, source, include, lib, and test directories with README files. Migrated and refactored the main LED blink code to src/src/main.c for ESP32 using Arduino framework. Updated .vscode/launch.json and added recommended extensions. Removed old Software/Codigo_SRI and replaced with Codigo_SRI.c.
2025-11-14 Initialize PlatformIO ESP32 project structure
    Added PlatformIO configuration, source, include, lib, and test directories with README files. Included a basic Arduino sketch for ESP32, VSCode workspace and extension recommendations, and removed ob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
2025-11-14 Add build output files for ESP32 project
    Generated build artifacts and dependency files for the ESP32 project using PlatformIO. Includes compiled object files, dependency lists, firmware binaries, and VSCode configuration updates.
2025-11-17 Migrate project to Arduino IDE structure
    Moved main source to Code/src/mainc.ino and added VSCode C++ properties for Arduino development. Removed PlatformIO configuration, related .gitignore, and documentation files to transition from Platf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
2025-11-17 Remove PlatformIO project and related files
    Deleted all files related to the PlatformIO ESP32 Arduino project, including configuration, source code, workspace settings, and documentation. This cleans up the repository by removing the project a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
2025-11-23 Refactor PWM and irrigation state variables
    Replaced single PWM_value variable with PWM_value_1, PWM_value_2, and PWM_value_3 for individual control. Added riego1_activo, riego2_activo, and riego3_activo state variables to track irrigation status for each zone. This improves code clarity and enables more granular control of irrigation and PWM outputs.
    [Codigo_SRI_Interface.ino]
2025-11-27 Update Codigo_SRI_Interface.ino and rebuild firmware
    Modified Software/src/Codigo_SRI_Interface.ino and rebuilt the ESP32 firmware. Binary and build artifacts updated to reflect the latest source changes.
2025-11-30 Revise flowchart for irrigation system logic
    cambio de diagrame de flujo
2025-11-30 Refactor variable memory layout in main firmware
    Adjusted the memory layout of global variables in Codigo_SRI_Interface.ino, including PWM_value_1, ntpServer, password, and ssid. This change optimizes data section alignment and may improve access e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
2025-12-03 se cambia de lugar la carpeta diagramas
2025-12-03 se agrega la carpeta circuitos
2025-12-05 Añadido de datasheets e informe final
2025-12-05 se sube el tiktok
2025-12-06 Se sube el informe final
2025-12-06 AXTUALIZACION Soportes
    [BaseDeTorres.stl, REDUCTOReducido.STL, SoporteServoBase.STL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]
